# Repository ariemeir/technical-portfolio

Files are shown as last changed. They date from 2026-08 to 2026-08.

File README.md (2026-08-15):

# Technical Portfolio — Arie Meir

Representative projects, published for reference.

**→ [Browse all source on GitHub](https://github.com/ariemeir/technical-portfolio)**

## Projects

### [RoboImplant](roboimplant/) — non-invasive spinal implant adjustment system

A motorized orthopedic implant that lengthens a spinal distraction rod without
surgery, for treating early-onset scoliosis in growing children. Full-stack
across four disciplines:

- **Embedded** — AVR C firmware on an ATmega1284P: real-time motor control via a
  DS1267 digital pot into a maxon ESCON servo controller, interrupt-driven
  rotation counting, and current-threshold coupling detection as the primary
  safety interlock.
- **Mobile** — Android clinician console over Bluetooth SPP, with a custom
  line-oriented ASCII protocol, live telemetry, 3D visualization, and patient
  records.
- **Electronics** — EAGLE schematic and board layout for the controller,
  including the analog current/voltage sensing chain.
- **Mechanical** — SolidWorks enclosure for the handheld driver unit.

<p align="center">
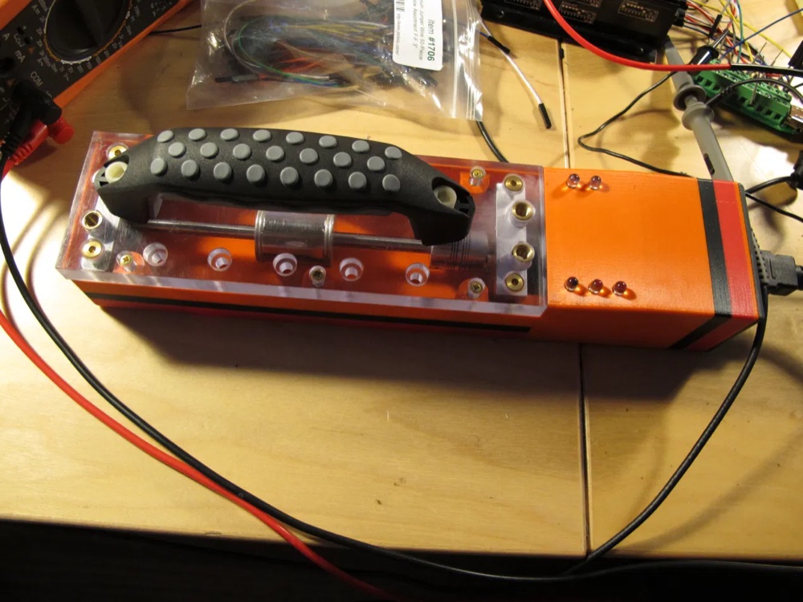
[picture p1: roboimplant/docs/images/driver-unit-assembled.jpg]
The assembled handheld driver unit in a 3D-printed orange enclosure with acrylic top plate.
  
  <br>
  <em>The handheld driver unit (v1)</em>
</p>

**→ [Read the one-page case study (PDF)](roboimplant/docs/roboimplant-case-study-arie-meir.pdf)**

Research prototype, ~2012–2013. Not a cleared medical device.
See [`roboimplant/NOTICE.md`](roboimplant/NOTICE.md) for rights and third-party
attribution.

---

### [3D Scanner](3dscanner/) — turntable photogrammetry rig

A DIY tabletop 3D scanner built to solve a real fabrication problem: an artist needed
larger and deeper variants of a commercially molded clay flower that existed only as a
physical object. It takes that object and produces a printable, watertight STL. Five
subsystems bound together by explicit contracts:

- **iOS** — **ScannerCam**, an iPhone camera server with a hand-rolled HTTP/1.1
  stack on `NWListener`: 13 REST routes, bearer auth with constant-time comparison,
  Keychain token storage, and hard locks on focus, exposure, and white balance.
  SwiftUI + AVFoundation, zero third-party packages.
- **Orchestration** — a Python session controller driving the scan loop across two
  machines, with idempotent retries, resumable sessions, and a five-stage SHA-256
  integrity chain from the phone's memory to the final archive.
- **Embedded** — an Arduino that controls the turntable by *impersonating its
  infrared remote*, replaying NEC codes reverse-engineered with a majority-vote
  capture sketch. No data port, no feedback, no encoder.
- **Reconstruction** — a Swift CLI over Apple Object Capture (RealityKit), chosen
  after COLMAP was tested and rejected for being CUDA-only on Apple Silicon.
- **Print prep** — a PyMeshLab pass that makes the mesh watertight, orients it by
  PCA, and scales it to real millimetres for printing and silicone-mold casting.

<p align="center">
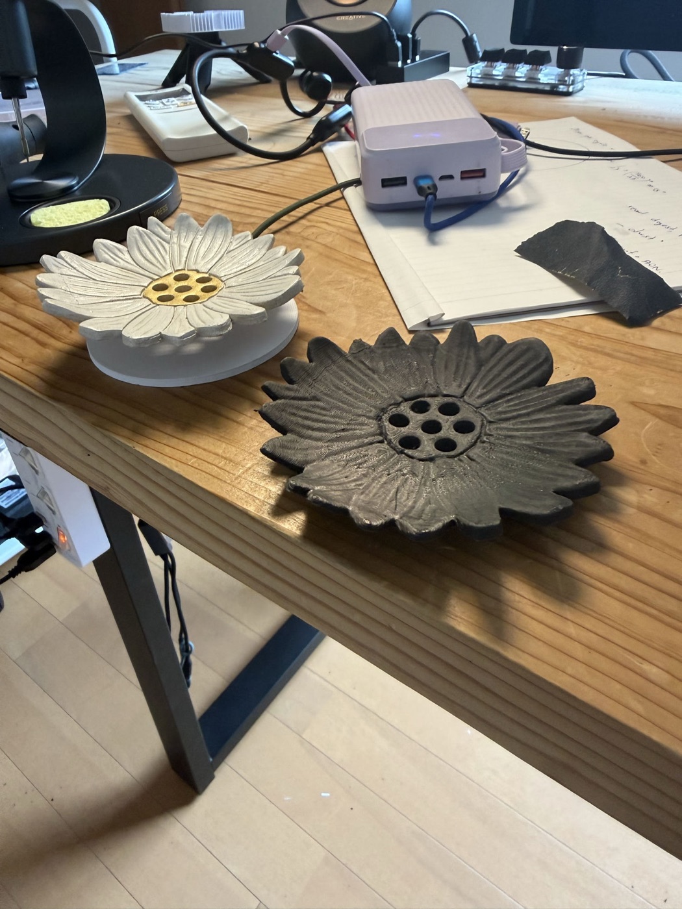
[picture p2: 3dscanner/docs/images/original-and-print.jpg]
A white ceramic daisy dish beside a dark grey 3D-printed copy of the same flower, both with ridged petals and a ring of holes through the centre.
  
  <br>
  <em>Input and output: the original ceramic dish, and a printed reproduction
  scanned from it.</em>
</p>

```
object ─→ 72 photos ─→ pose solve ─→ textured mesh ─→ watertight STL ─→ printed master
          locked        Object          USDZ/OBJ        PyMeshLab         silicone mold
          optics        Capture                         repair            → cast copies
```

The engineering centrepiece is control of an actuator that cannot be observed: the
turntable answers only to a fire-and-forget infrared *toggle*, so the controller
tracks an explicit assumed state and halts for human realignment on any ambiguity
rather than guessing and silently desynchronising the scan.

**→ [Read the one-page case study (PDF)](3dscanner/docs/3dscanner-case-study-arie-meir.pdf)**
· [Engineering log](3dscanner/docs/engineering-log.md)
· [Technical spec](3dscanner/docs/scannercam_spec.md)

Personal project, 2026. Working single-operator rig at late-prototype maturity.
See [`3dscanner/NOTICE.md`](3dscanner/NOTICE.md) for rights and attribution.

---

### [WifeSignal](wifesignal/) — a traffic light for the office door

A three-colour desk lamp that lets one person in the house tell another *how much
this can wait*. The office is a separate building: music on, windows closed, phone
face-down and unchecked for hours — which is the point, and which makes it a sealed
box. Text-and-hope fails when it matters; walking over always costs an interruption
whether or not the thing was urgent. The missing piece was never notification, it
was **priority expressed before the interruption happens**. Five components across
four disciplines:

- **iOS** — a SwiftUI app in 333 lines with no third-party packages and no
  Bluetooth: three priority buttons, a 5 s status poll, and a *Waiting… → Seen ♥*
  acknowledgement card that closes the loop for the sender.
- **Server** — a 290-line aiohttp + bleak bridge on a Mac, sharing one asyncio event
  loop, that exists because an iPhone cannot reliably be a BLE central for a device
  in another building. Bearer auth with constant-time comparison, exposed to a
  Tailscale tailnet only.
- **Embedded** — ESP32-C3 firmware over NimBLE exposing one service, one
  characteristic, one byte, with physical button presses as the acknowledgement path.
- **Electronics** — a custom two-layer KiCad board: three low-side lamp drivers,
  entirely through-hole, shaped and notched to match the enclosure.
- **Mechanical** — a 440-line Fusion 360 *script* that generates the two-part
  enclosure from derived dimensions, versioned in-band and guarded step by step.

<p align="center">
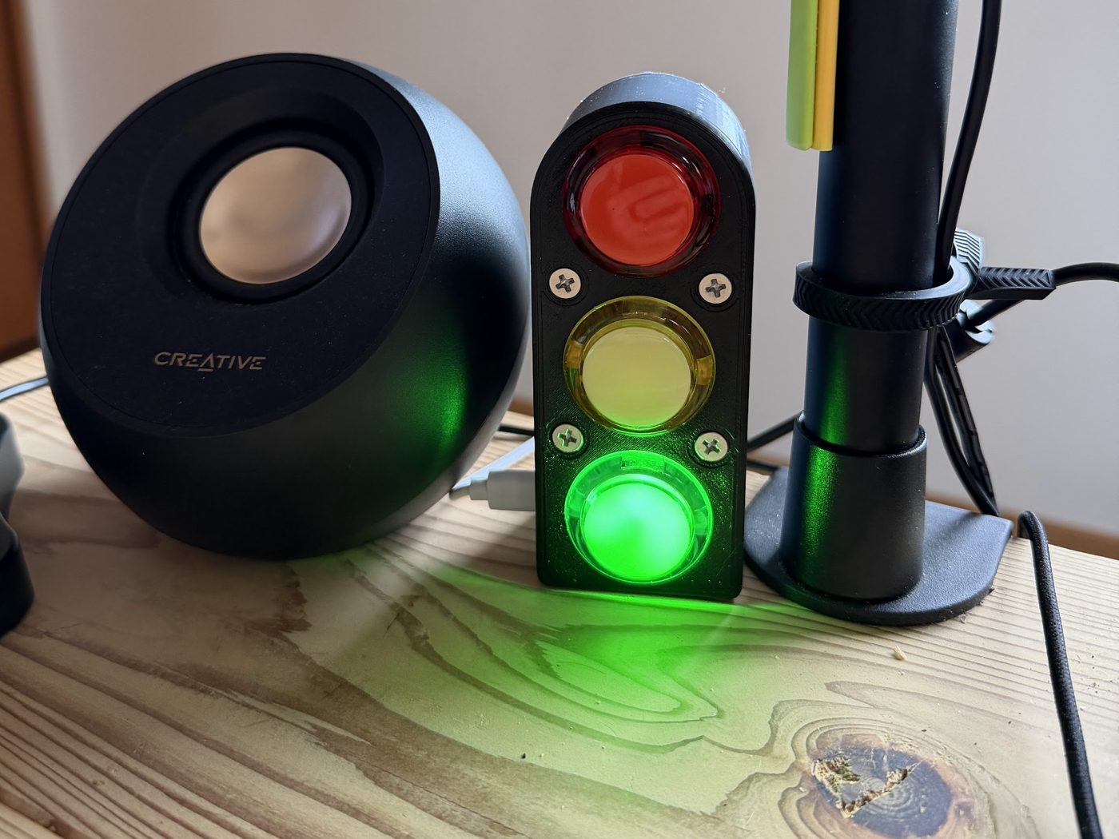
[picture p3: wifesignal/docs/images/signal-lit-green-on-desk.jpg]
A small black 3D-printed traffic light standing on a pale wooden desk beside a round black speaker. Its red and yellow lenses are dark; the bottom green lens glows brightly and casts a pool of green light across the desk.
  
  <br>
  <em>Green — <strong>whenever you're free</strong>. The speaker beside it is the
  reason the project exists.</em>
</p>

```
tap ─→ HTTPS ─→ aiohttp ─→ 1 byte ─→ ESP32-C3 ─→ lamp ─→ physical ─→ "Seen ♥"
       tailnet   desired    over BLE   NimBLE              press       on her
       only      state                                     = ack       phone
```

The engineering centrepiece is the return path. Because the state characteristic is
bidirectional, three different events — the server's own write echoed back, a human
pressing the button, and a device that has drifted — all arrive as an identical
one-byte notification. They are separated with no timers, correlation IDs, or
sequence numbers: every notify is simply compared against the state the server
already intends, which collapses the whole problem into three branches and makes
recovery after a reboot or a reflash automatic.

**→ [Read the one-page case study (PDF)](wifesignal/docs/wifesignal-case-study-arie-meir.pdf)**
· [Full case study](wifesignal/) · [Server](wifesignal/server/) · [iOS app](wifesignal/app/)
· [Firmware](wifesignal/firmware/) · [Hardware](wifesignal/device/)

Personal project, 2026. In daily use.
See [`wifesignal/NOTICE.md`](wifesignal/NOTICE.md) for rights and attribution.

---

Each project directory carries its own README and rights notice. Unless stated
otherwise in a project's `NOTICE.md`, this work is published for reference only
and is not offered under an open-source license.

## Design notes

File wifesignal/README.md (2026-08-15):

# WifeSignal — A Traffic Light for the Office Door

A three-colour desk lamp that lets one person in the house tell another *how much
this can wait*, without a phone, a notification, or an interruption. An iPhone app
sends a priority; a Mac in the office translates it to Bluetooth Low Energy; a
custom PCB lights one of three illuminated arcade buttons. Pressing that button
acknowledges the message, and the sender's phone shows **Seen ♥**.

<p align="center">
  A small black 3D-printed traffic light standing on a pale wooden desk beside a round black speaker. Its top lens is red and its middle lens is yellow, both dark; the bottom lens glows bright green and casts a pool of green light across the desk surface.
  <br>
  <em>The whole point of the project in one frame: green — <strong>whenever you're
  free</strong>. The speaker beside it is the reason the system exists. With music
  on and the windows closed, the office is acoustically sealed off from the house,
  and the phone is face-down and ignored on purpose. The light is the one channel
  that gets through without breaking concentration.</em>
</p>

Built 2026. Author: Arie Meir. Personal project — see [NOTICE.md](NOTICE.md).

**→ [Read the one-page case study (PDF)](docs/wifesignal-case-study-arie-meir.pdf)**
· [Server](server/) · [iOS app](app/) · [Firmware](firmware/) · [Hardware](device/)
· [Browse the source on GitHub](https://github.com/ariemeir/technical-portfolio/tree/main/wifesignal)

> **Reference only.** A working system in daily use, published so the engineering
> can be read. Deployment specifics (signing team, App Store Connect key IDs,
> Tailscale hostname, absolute paths) have been replaced with placeholders. No
> credential or token appears anywhere in this directory.

---

## The problem

The office is a separate building, a short walk from the house. Work there happens
with music on and the windows closed, which is exactly the point — and which makes
it a sealed box. The phone is face-down and unchecked for hours at a time, by
design.

That produces a genuinely asymmetric problem for the household. A message that
means *call your mother back sometime this week* and a message that means *the
delivery driver is leaving in thirty seconds* arrive through the same silent
channel and get read at the same time, which is to say eventually. The available
options were both bad: text and hope, which fails when it matters, or walk over,
which always works and always costs an interruption regardless of whether the
thing was urgent.

The missing piece was never notification. It was **priority, expressed before the
interruption happens**. The system had to satisfy four constraints:

- **Glanceable, not readable.** The signal must land in peripheral vision without
  pulling attention into a screen. Deciding whether to break focus should not
  itself break focus.
- **Three levels, not a text box.** Composing a message is work for the sender and
  ambiguity for the receiver. Three buttons removes both.
- **Acknowledgement must flow back.** A signal that vanishes into silence is worse
  than no signal — the sender is left wondering whether to walk over anyway. The
  loop only closes when she can see that it landed.
- **It cannot depend on the phone being looked at.** Which rules out every
  push-notification solution, since that is the failure mode being designed around.

The result is a shared vocabulary of three words — **Whenever**, **Soon**, **Now**
— with a physical object in the room that speaks it.

<p align="center">
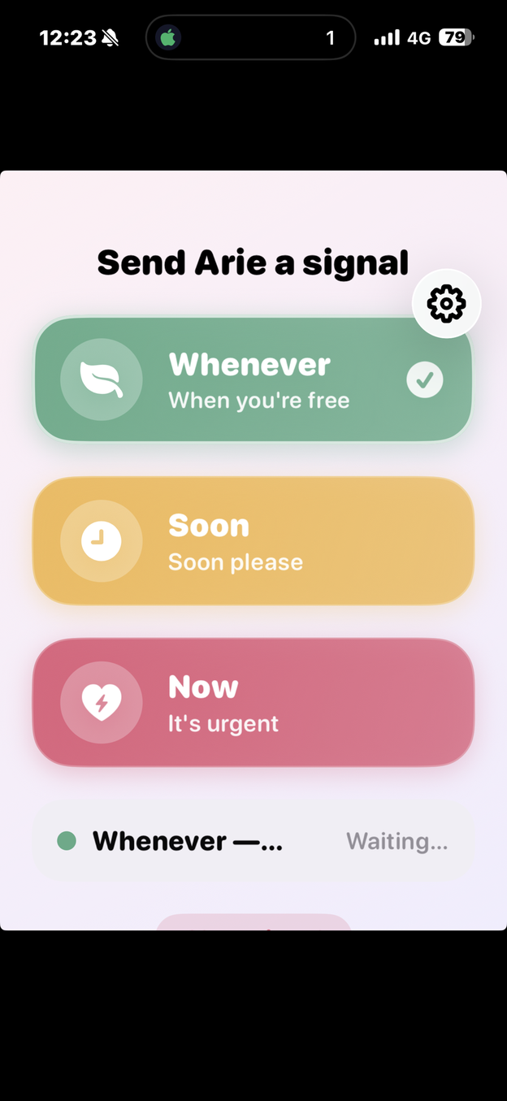
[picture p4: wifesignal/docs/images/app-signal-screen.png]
An iPhone screen titled 'Send Arie a signal' with three large rounded buttons stacked vertically: a green one labelled Whenever, 'When you're free', with a leaf icon and a tick; a yellow one labelled Soon, 'Soon please', with a clock icon; and a red one labelled Now, 'It's urgent', with a heart-and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
  
  <br>
  <em>The sender's whole interface. The palette is deliberately soft — the urgent
  case is a <em>rose</em>, not a fire-alarm red, and its icon is
  <code>bolt.heart.fill</code>. This is a channel between two people who like each
  other, not an alerting console. The status row is the acknowledgement path:
  <strong>Waiting…</strong> until the button is physically pressed, then
  <strong>Seen ♥</strong>.</em>
</p>

## How it works

Five components, four protocol boundaries, and one byte that carries the entire
system state.

```
┌─────────────┐   HTTPS + Bearer    ┌──────────────────┐    BLE GATT    ┌──────────────┐
│  iPhone app │ ──────────────────► │  aiohttp server  │ ─────────────► │  ESP32-C3    │
│  (SwiftUI)  │   tailnet only      │  (Mac, launchd)  │   1 byte       │  + 3 lamps   │
│             │ ◄────────────────── │                  │ ◄───────────── │              │
└─────────────┘   GET /v1/status    └──────────────────┘   NOTIFY       └──────────────┘
                  every 5 s                                             physical press
                                                                        = acknowledge
```

The architectural keystone is the middle box, and it exists for one reason: **an
iPhone cannot be a reliable BLE central for a device in another building.** iOS
suspends background Bluetooth work aggressively, and the phone is frequently not
in the office at all. So the phone never speaks Bluetooth. A Mac that is already
sitting three metres from the lamp, already powered, already on the network, takes
that role permanently. Everything else in the stack — the Tailscale tunnel, the
launchd job, the macOS Bluetooth permission grants — is the price of that single
decision, and it is worth paying: the phone's job shrinks to an authenticated HTTP
POST, which is a thing phones do perfectly.

Transport is [Tailscale](https://tailscale.com) `serve`, not a public tunnel. The
API is reachable only from devices on the tailnet, over a real Let's Encrypt
certificate, with the second phone joined by **node sharing** so it resolves the
one host and sees nothing else on the network. The bearer token is the inner
layer; the tailnet ACL is the wall.

## One byte on the wire

The BLE contract is a single characteristic carrying a single byte:

| Value | Meaning |
|---|---|
| `0x00` | all lamps off |
| `0x01` | red — *Now* |
| `0x02` | yellow — *Soon* |
| `0x03` | green — *Whenever* |

Three channels addressed **by value, not by bitmask**. That choice is doing real
work. The product rule is *exactly one signal is active at a time*, and encoding
the channels as a bitmask would have made "red and green simultaneously" a
representable state — one that every layer would then need to defend against. As
an enumeration, the illegal state cannot be expressed on the wire at all. There is
no validation code for it anywhere in the server or the firmware, because there is
nothing to validate.

The same byte is read, written, and notified, which is what makes the
acknowledgement path collapse into almost nothing: the device does not need a
separate "ack" message, because setting the state to `0` *is* the acknowledgement.

## Telling your own echo from a human being

This is the interesting problem in the system, and it comes directly from that
economy. Because the state byte is bidirectional, the server has to distinguish
three events that arrive through the identical mechanism — a `NOTIFY` carrying one
byte:

1. **Its own write, echoed back.** The firmware notifies subscribers whenever the
   characteristic changes, including when the change came from the server itself.
2. **A physical button press**, which is the acknowledgement and the entire reason
   the return path exists.
3. **Drift** — the device holding a state that disagrees with the server, after a
   reboot, a reflash, or a button press while idle.

The conventional fixes are correlation IDs, sequence numbers, or a suppression
window timed around each write. All three add state, and the timer-based one is
subtly wrong under load. The server instead exploits the fact that it already
knows what the lamps *should* show, in a variable named `desired_state`, and
classifies every incoming notify by comparing against it:

| Notify value | vs. `desired_state` | Interpretation | Action |
|---|---|---|---|
| equal | — | echo of our own write | ignore |
| `0` | non-zero | **physical press** | mark acknowledged, timestamp it |
| anything else | mismatch | drift | re-assert `desired_state` |

Three branches, no timers, no message IDs, no sequence numbers. The third branch is
load-bearing in a way that is easy to miss: it is simultaneously the anti-drift
mechanism *and* the hook for a future "ping back" feature, where a press from idle
would signal in the other direction. Today the server writes that press straight
back to off, which is the correct conservative behaviour for a feature whose
semantics have not been decided.

## Converging instead of queueing

`desired_state` is defined as a pure function of the signal: *the colour byte iff a
signal is active and un-acknowledged, else zero.* HTTP handlers never touch
Bluetooth. They mutate state under an `asyncio.Lock` and set an
`asyncio.Event`; a single BLE task owns the `BleakClient` and performs every write.

There is **no queue and no retry list**, which is the point. A burst of taps
coalesces into one write of the latest value, because last-write-wins is exactly
right for a lamp — nobody wants a backlog of stale colours replayed at them. More
importantly, the same property makes recovery free. The reconnect loop re-writes
`desired_state` immediately on every successful connect, so a device that rebooted,
lost power, or was reflashed mid-signal comes back showing the correct colour
without anyone noticing, and without a single line of reconciliation logic.

Convergence, not delivery. The server never asks *did that message arrive?* — it
continuously asserts *this is what the lamps should show*, and any disagreement
resolves itself on the next connect. Around it sits an ordinary supervisor:
scan by service UUID, connect, subscribe, race the write-needed and disconnected
events, and back off exponentially from 1 s to a 30 s ceiling on failure.

## The soldered parts win

The lamp drivers on the assembled board are **S8550 PNP** transistors. The
schematic says **S8050 NPN**. They came from the same assortment kit, the part
numbers differ by one character, and the mistake was found only after the board was
populated and the lamps behaved backwards.

A PNP low-side driver inverts the control logic: **GPIO LOW turns the lamp on.**
The fix was one line in `applyLamps()` and a comment in capital letters telling the
next engineer not to "correct" it back. Reworking three transistors on a working
board would have bought nothing except the satisfaction of matching a drawing.

The second-order consequence was subtler and took longer to find. A pin that has
not yet been configured as an output floats, and a floating base on a PNP driver
reads as *on* — so all three lamps flashed at every boot. The fix is an ordering
trick that is worth knowing: **drive the pin high, then call `pinMode(OUTPUT)`,
then drive it high again.** The first write latches the level into the output
register before the driver is enabled, so the pin never passes through an undefined
state on its way to being an output.

The schematic in this repository is therefore **knowingly wrong**, and documented
as such. That is the honest artifact of a physical project: the drawing describes
an intention, the board describes reality, and the firmware is written against
reality.

## Failures that make no sound

Every hard bug in this project failed silently. None threw an exception; all of
them just quietly did nothing, which is the worst possible behaviour and the reason
the codebase is structured around detecting symptoms rather than catching errors.

**macOS returns empty Bluetooth scans when permission is missing.** Not an error,
not a prompt — an empty list, indistinguishable from "no devices nearby". The scan
function therefore counts how many advertisements it saw *at all*, and when the
count is zero it logs a warning naming the actual cause and the exact System
Settings pane. The launchd-run interpreter needs its own grant, separate from the
one Terminal inherits, and the grant is attached to the Python binary's path — so a
Homebrew upgrade silently revokes it.

**macOS also hides advertised device names**, returning `None` for all of them, so
name-based matching finds nothing forever. All matching in this project is by
service UUID, in three separate files, each with a comment explaining why.

**A `snake_case` JSON key would have silently decoded to `nil`** in Swift rather
than throwing. The server's responses are deliberately camelCase (`sentAt`,
`acknowledgedAt`) with a comment on both sides of the boundary recording that the
iOS app decodes with a bare `JSONDecoder` and would drop the timestamps without
complaint.

**A folder move broke the LaunchAgent without a single log line.** Absolute paths
in the plist and in the ops script pointed at the old location; launchd simply
declined to start the job. In the published copy those paths are placeholders
(`__PROJECT_DIR__`, `__HOME__`) and the ops script derives its own location, which
is what should have been true from the start.

**The device accepts exactly one BLE central.** The test CLI and the server cannot
both be connected, and the failure looks like an unrelated timeout. Documented at
the top of every file that connects.

## From breadboard to fabricated board

Four stages, roughly two weeks, each one earning the next.

| | |
|:--:|:--:|
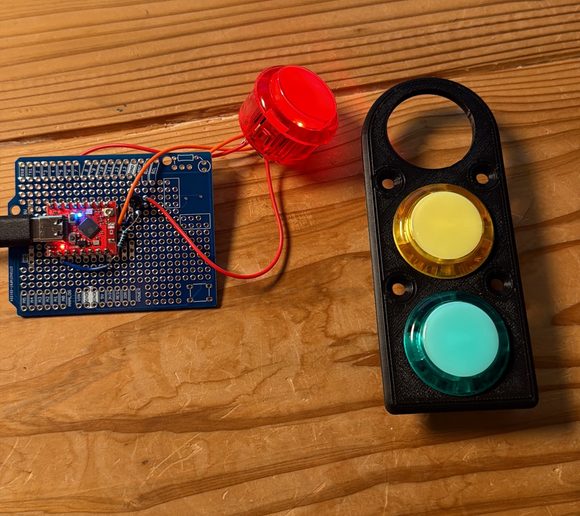
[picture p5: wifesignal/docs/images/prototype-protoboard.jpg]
An Arduino-style prototyping shield on blue perfboard with a small red microcontroller board soldered to it, wired with red jumper wire to a single large red illuminated arcade button. Beside it lies a black 3D-printed faceplate holding a yellow and a green arcade button, with an empty circular cut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
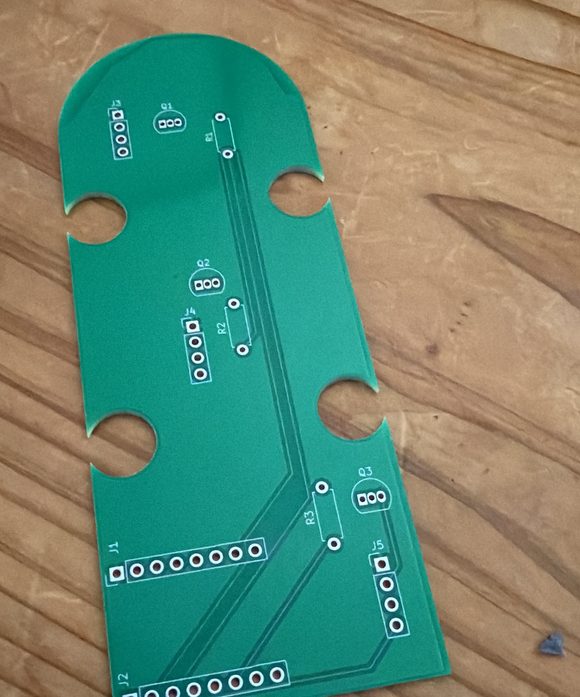
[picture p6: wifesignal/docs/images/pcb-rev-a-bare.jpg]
A bare green printed circuit board on a wooden desk, rounded at one end and square at the other, with four semicircular notches cut into its long edges. White silkscreen marks three transistor outlines labelled Q1, Q2 and Q3, three resistor footprints R1 to R3, and two eight-pin headers J1 and J2.
|  |  |
| **1. One channel on protoboard.** A single button and lamp, proving the BLE service, the button semantics and the inverted lamp polarity before committing to a layout. The faceplate beside it is already the target shape. | **2. Rev A, fabricated.** Three identical channels: GPIO → 1 kΩ → transistor base, emitter to ground, collector to lamp cathode. Entirely through-hole, two layers, no vias. The four edge notches are not decoration — see below. |
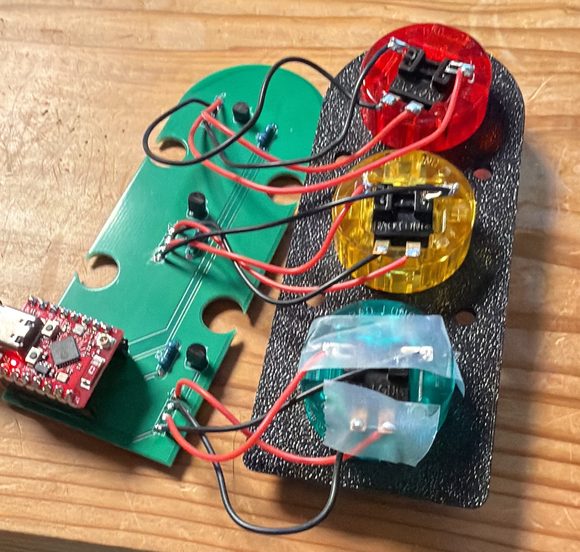
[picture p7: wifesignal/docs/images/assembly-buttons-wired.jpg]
The green circuit board wired to a black 3D-printed faceplate holding red, yellow and green illuminated arcade buttons. Red and black wire pairs run from board headers to each button's lamp and switch terminals. A small red ESP32-C3 module is seated on female headers at the lower left of the board.
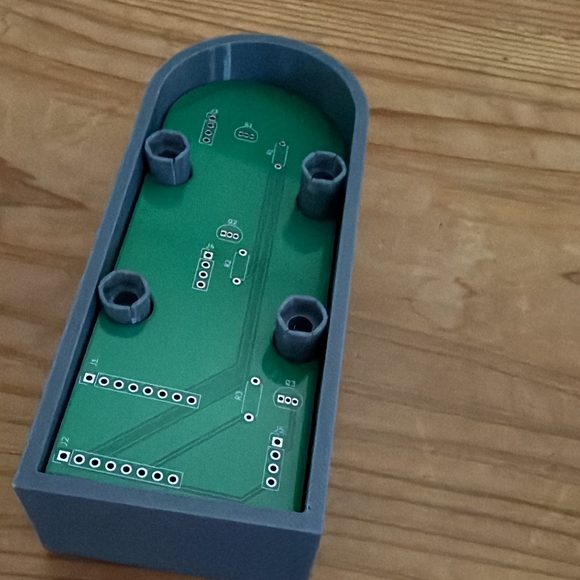
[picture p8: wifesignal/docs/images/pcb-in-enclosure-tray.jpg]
The green circuit board resting inside a grey 3D-printed tray, supported on four dark hexagonal pillars that pass through the notches in the board's edges. A yellow sticky note lies on the desk above.
|  |  |
| **3. Assembled.** The ESP32-C3 sits on female headers, so it is removable and the board is not scrap if the module dies. Each button is a four-wire part: lamp anode and cathode, switch common and normally-open. | **4. In the enclosure.** The board drops over four M4 pillars — the notches at (±16, ±18.5) mm are cut to clear them exactly. The electrical and mechanical designs are dimensionally coupled, and both say so in comments. |

The pin assignment carries one hard-won rule: **GPIO 2, 8 and 9 are strapping pins
and 20/21 are UART0** on the ESP32-C3, so all five are avoided. Strapping pins are
sampled at boot to decide boot mode; hanging a lamp driver off one produces a board
that works perfectly until the day it refuses to start.

| | Red | Yellow | Green |
|---|---|---|---|
| **switch** | GPIO3 | GPIO4 | GPIO5 |
| **lamp** | GPIO6 | GPIO7 | GPIO10 |

Buttons are `INPUT_PULLUP` with common tied to ground, so a press reads LOW,
debounced at 40 ms with a per-button handled flag.

## An enclosure that is a program

The enclosure is not an STL and not a saved CAD file. It is a **440-line Python
script that generates the entire two-part enclosure inside Autodesk Fusion 360**,
and it is the declared source of truth — the design is rebuilt from code, not
edited by hand.

That is not novelty for its own sake. It buys the same things version-controlled
code always buys, in a domain where they are usually unavailable:

- **Dimensions are derived, not typed.** The body width is
  `BUTTON_HOLE_DIA + 2 × SIDE_MARGIN`; the height is `BUTTON_SPACING × 2 + 2 ×
  END_MARGIN`. Changing the button diameter reshapes the whole enclosure
  consistently, instead of leaving four stale numbers behind.
- **Physical measurements are named constants.** The USB-C window's vertical extent
  is computed from the measured height of the connector above the PCB and the
  thickness of the spacer stack, not eyeballed against a screen.
- **The build is versioned in-band.** `VERSION = "v15"` with a build stamp, printed
  to a dialog on completion, so the running copy can be identified — the script
  lives in two places and drift is otherwise invisible.
- **Fragile operations are individually guarded.** Fillets and countersinks are the
  features most likely to fail on a given geometry, so each is wrapped and reports
  `built | FAILED | skipped` rather than aborting the run and losing everything.

The visible result of iterating in code is a redesign that would have been painful
by hand: v12 held the bare dev board on edge in a printed cradle; v15 deletes the
cradle entirely, deepens the tray from 30 mm to 37 mm, and bolts the custom PCB
flat to four pillars — the change that turned a prototype holder into a product.

## Repository layout

| Path | Contents |
|---|---|
| [`server/`](server/) | The whole bridge: aiohttp HTTP API + bleak BLE central, 290 lines, one file, one event loop. Plus a standalone BLE test CLI. |
| [`app/`](app/) | SwiftUI iPhone app, 333 lines across 7 files. XcodeGen spec; no `.xcodeproj` in the repo. |
| [`firmware/`](firmware/) | ESP32-C3 firmware (NimBLE-Arduino). The current 3-channel build, plus the 1-channel bring-up sketch kept as reference. |
| [`device/WifeSignalPCB/`](device/WifeSignalPCB/) | KiCad project and fabrication output. `WifeSignal3ch` is the board that was made. |
| [`device/enclosure/`](device/enclosure/) | The Fusion 360 generator script — the CAD source of truth. |
| [`ops/`](ops/) | launchd LaunchAgent template and the `up/down/restart/status/logs/ack` operator script. |

## The HTTP API

All JSON, all bearer-authenticated except `/health`, which ops tooling needs to
reach before it can know whether anything else works.

| Method | Path | Purpose |
|---|---|---|
| `POST` | `/v1/signal` | `{"color": "green"\|"yellow"\|"red"}` — set the signal, light the lamp |
| `POST` | `/v1/clear` | Wipe the signal, all lamps off |
| `POST` | `/v1/ack` | Acknowledge without clearing the colour — the CLI equivalent of a physical press |
| `GET` | `/v1/status` | Polled by the app every 5 s |
| `GET` | `/health` | Unauthenticated; reports `deviceConnected` |

Token comparison is constant-time via `hmac.compare_digest`, and the server refuses
to start with an empty token rather than defaulting to open. Device liveness is
surfaced to the app as a soft field rather than an error, so a disconnected lamp
degrades the UI instead of breaking it.

## The BLE contract

| | |
|---|---|
| Service UUID | `6d5f0001-4b6b-4a3a-9e1e-2a7b1c9f0001` |
| STATE characteristic | `6d5f0002-4b6b-4a3a-9e1e-2a7b1c9f0002` |
| Properties | `READ` \| `WRITE` \| `NOTIFY`, 1 byte |
| Advertising | Service UUID in the advertisement, 100–200 ms interval |
| Matching | **By service UUID only** — macOS reports advertised names as `None` |

Firmware button semantics, which must stay in lockstep with the server's
classification table: a press while `state != 0` sets `0` and notifies (that is the
acknowledgement); a press while `state == 0` sets that button's colour, which the
server writes back off.

## State of the code

A working system in daily use, honestly described. What that means:

- **The acknowledgement is not instant.** It arrives on the next 5 s poll. A
  WebSocket rewrite was considered and explicitly rejected — polling is
  imperceptible at this cadence and the HTTP stack was already deployed and proven.
- **The app only sees acknowledgements while foregrounded.** Polling is a plain
  `Task` loop that never pauses in the background, and there is no
  `BGTaskScheduler` and no push. For the sender's actual usage — open the app, tap,
  watch for *Seen* — this is fine, and it is still a real limitation.
- **Poll failures after the first success are swallowed.** The error is only
  surfaced when there is no status at all, so a server that dies mid-session leaves
  the last-known state on screen without a warning.
- **The API token lives in `UserDefaults`, not the Keychain.** Acceptable only
  because the API is tailnet-only and can do nothing but change a lamp colour; it
  should still be in the Keychain.
- **URL validation is `URL(string:) != nil`**, which accepts very nearly anything.
- **The schematic disagrees with the built board** on the transistor part number,
  deliberately and with the reason documented in three places.
- **The 1-channel PCB variant was never routed or fabricated.** It is kept as a
  design-history artifact; only `WifeSignal3ch` exists physically.
- **A "ping back" path is stubbed but not designed.** The hook is live in the
  notify handler; the semantics are undecided, so a press from idle is currently
  written straight back to off.

## Key sources

| File | Why it's worth reading |
|---|---|
| [`server/server.py`](https://github.com/ariemeir/technical-portfolio/blob/main/wifesignal/server/server.py) | The whole bridge in 290 lines. The `on_notify` classifier and the `ble_loop` supervisor are the heart of the system. |
| [`firmware/wifesignal_3ch/wifesignal_3ch.ino`](https://github.com/ariemeir/technical-portfolio/blob/main/wifesignal/firmware/wifesignal_3ch/wifesignal_3ch.ino) | The PNP polarity note and the latch-before-`pinMode` boot-flash fix, with the button semantics documented as a contract with the server. |
| [`app/WifeSignal/SignalViewModel.swift`](https://github.com/ariemeir/technical-portfolio/blob/main/wifesignal/app/WifeSignal/SignalViewModel.swift) | 38 lines: the poll loop and its deliberately forgiving — and knowingly flawed — error policy. |
| [`app/WifeSignal/ContentView.swift`](https://github.com/ariemeir/technical-portfolio/blob/main/wifesignal/app/WifeSignal/ContentView.swift) | The entire UI, including the *Waiting… → Seen ♥* status card. |
| [`device/enclosure/AWifeSignalEnclosure.py`](https://github.com/ariemeir/technical-portfolio/blob/main/wifesignal/device/enclosure/AWifeSignalEnclosure.py) | Parametric CAD as a program: derived dimensions, measured constants, guarded feature steps. |
| [`device/WifeSignalPCB/WifeSignal3ch.kicad_sch`](https://github.com/ariemeir/technical-portfolio/blob/main/wifesignal/device/WifeSignalPCB/WifeSignal3ch.kicad_sch) | The schematic, including the in-drawing notes mapping refs to channels — and the wrong transistor. |
| [`ops/wife-signal`](https://github.com/ariemeir/technical-portfolio/blob/main/wifesignal/ops/wife-signal) | launchd bootstrap, health polling, and Tailscale serve configuration in one operator script. |
| [`server/wifesignal_cli.py`](https://github.com/ariemeir/technical-portfolio/blob/main/wifesignal/server/wifesignal_cli.py) | 69-line BLE REPL for talking to the board directly when the server is stopped. |

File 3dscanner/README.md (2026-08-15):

# 3D Scanner — Turntable Photogrammetry Rig

A DIY tabletop 3D scanner that turns a physical object into a printable, watertight
STL. An iPhone runs a from-scratch HTTP camera server; a Mac orchestrates the scan;
an Arduino drives the turntable by impersonating its infrared remote; Apple Object
Capture reconstructs the mesh; a PyMeshLab pass prepares it for printing and casting.

<p align="center">
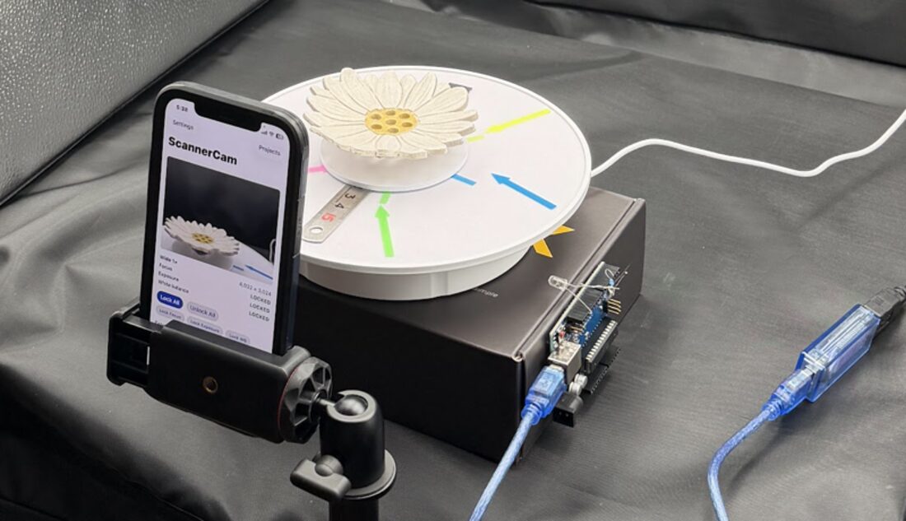
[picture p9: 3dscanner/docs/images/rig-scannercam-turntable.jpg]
Close view of the rig: an iPhone running ScannerCam on a tripod mount showing a live preview and three status rows reading LOCKED, facing a white turntable holding a ceramic daisy dish, with an Arduino and its infrared LED aimed at the turntable from the right.
  
  <br>
  <em>The whole capture loop in one frame. The phone runs <strong>ScannerCam</strong>
  with focus, exposure and white balance all reading <code>LOCKED</code> — a state the
  controller can <em>require</em> before it will record a single frame. At right, the
  Arduino's IR LED points at the turntable across open air: the only link between them,
  and a one-way one.</em>
</p>

Built 2026. Author: Arie Meir. Personal project — see [NOTICE.md](NOTICE.md).

**→ [Read the one-page case study (PDF)](docs/3dscanner-case-study-arie-meir.pdf)**
· [Engineering log](docs/engineering-log.md)
· [ScannerCam technical spec](docs/scannercam_spec.md)
· [Browse the source on GitHub](https://github.com/ariemeir/technical-portfolio/tree/main/3dscanner)

> **Reference only.** A working single-operator rig at late-prototype maturity,
> published so the engineering can be read. Deployment specifics (device IDs,
> network addresses, signing team) have been replaced with placeholders.

---

## The problem

An artist wanted **larger versions of a commercially molded clay flower**, and to
explore deeper forms without changing the diameter. The obstacle was that the
geometry existed only as a physical object — there was no model to scale, deepen, or
re-cut. Getting one meant capturing the real surface accurately enough to modify,
re-fabricate, and eventually use as the basis for new mold tooling.

Photogrammetry — reconstructing 3D geometry from overlapping photographs — is the
right tool, but it needs dozens of images from evenly spaced angles shot under
*identical* optical conditions. Commercial turntable scanners exist and cost
accordingly. The parts to build one do not: a motorized photography turntable is
inexpensive, and a modern phone has a better sensor than most dedicated scanner
cameras.

The gap is control. The turntable obeys an infrared remote and has no data port.
The phone's camera app will happily refocus and re-meter between shots, which
destroys the reconstruction. Nothing talks to anything else.

This project closes that gap end-to-end: object in, printable mesh out, with every
frame verified byte-for-byte along the way — and the loop is closed, since the
scanned flower came back as a printed reproduction.

## How it works

```
   ┌──────────────┐                            ┌────────────────────────────┐
   │ IR remote    │  reverse-engineered        │  iPhone — "saru"           │
   │ 14 NEC codes │  → turntable_codes.json    │  ScannerCam (SwiftUI)      │
   └──────┬───────┘                            │  ┌──────────────────────┐  │
          │ replayed                           │  │ HTTP/1.1 server      │  │
          ▼                                    │  │ NWListener, 13 routes│  │
   ┌──────────────┐   serial ASCII 115200      │  │ bearer auth          │  │
   │ Arduino Uno  │◄───────────────────┐       │  └──────────┬───────────┘  │
   │ IR LED / D3  │  PING→PONG         │       │  AVCapture: focus/exposure │
   └──────┬───────┘  R <rawhex>        │       │  /WB LOCKED for the run    │
          │ 38 kHz                     │       └─────────────┬──────────────┘
          ▼                            │                     │ HTTP over
   ┌──────────────┐                    │                     │ Wi-Fi / Tailscale
   │  turntable   │            ┌───────┴─────────────────────┴───────┐
   │  (no data    │            │        Mac — "shika"                │
   │   port)      │            │  scan.py — session controller       │
   └──────────────┘            │  move → settle → capture → pull →   │
                               │  SHA-256 verify → next frame        │
                               └──────────────────┬──────────────────┘
                                                  │  scans/completed/<id>/
                                                  ▼  + tar.gz + checksums
                               ┌─────────────────────────────────────┐
                               │  Apple Object Capture (RealityKit)  │
                               │  objcap CLI → USDZ + OBJ → STL      │
                               └──────────────────┬──────────────────┘
                                                  ▼
                               ┌─────────────────────────────────────┐
                               │  repair.py (PyMeshLab)              │
                               │  weld → drop strays → close holes → │
                               │  orient → scale to mm → watertight  │
                               └─────────────────────────────────────┘
```

One scan is 36–72 frames. Each frame is: rotate by a timed IR pulse, wait for
vibration to settle, trigger the shutter over HTTP, download the JPEG, verify its
SHA-256, then move again. A 72-frame run plus reconstruction takes roughly five
minutes per loop on an M4.

<p align="center">
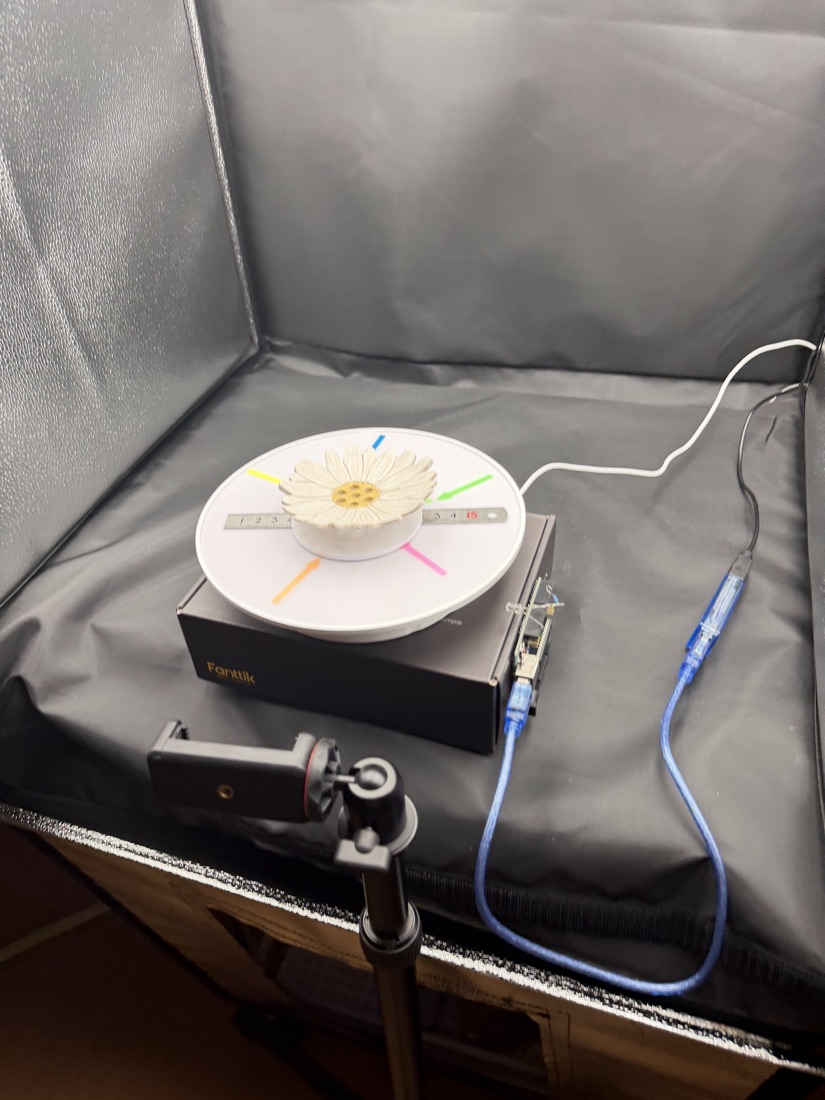
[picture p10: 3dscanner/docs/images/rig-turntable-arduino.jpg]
The motorized turntable raised on a box inside the light tent, with the Arduino board beside it and its infrared LED aimed at the turntable.
  
  <br>
  <em>The Arduino's IR LED, aimed across open air at the turntable — no wire connects
  them. The exact command codes were learned from the turntable's own remote using
  <code>capture_remote_signals.ino</code>, then replayed.</em>
</p>

The two machines carry codenames throughout the code and docs: **`saru`** is the
iPhone, **`shika`** is the Mac.

## Driving an actuator you cannot observe

This is the interesting control problem, and it shaped the whole controller.

<p align="center">
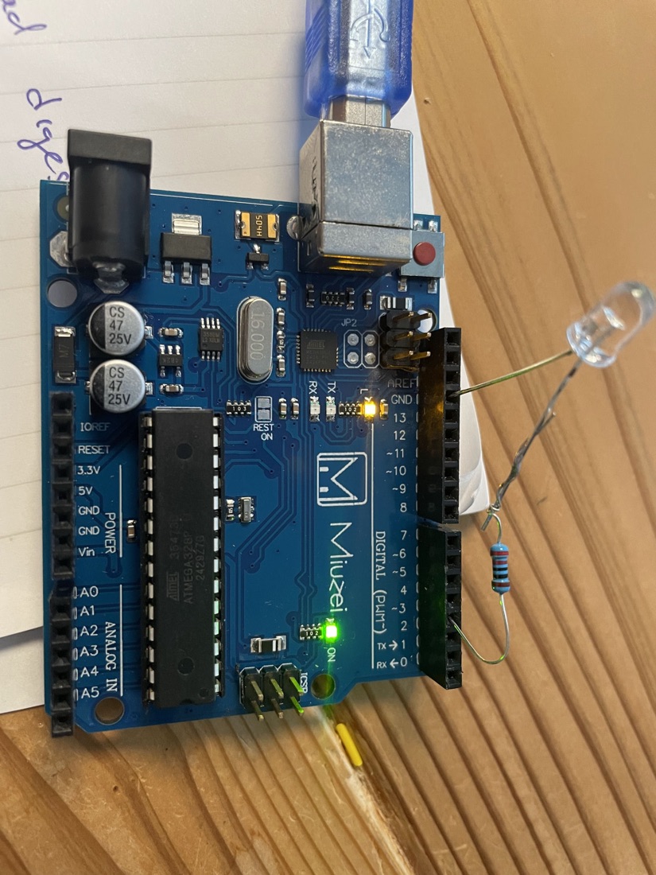
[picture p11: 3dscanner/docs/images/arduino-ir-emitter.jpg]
Close-up of an Arduino Uno with a clear infrared LED wired through a series resistor to the digital header, connected to a computer by a blue USB cable.
  
  <br>
  <em>The entire electrical interface to the turntable: one infrared LED on a series
  resistor, run off the Uno's digital header. <strong>Nothing connects to the turntable
  at all</strong> — it has no data port, so the Arduino simply impersonates its remote.
  The LED emits outside the visible band, so it looks equally dead whether or not it is
  working, which is exactly why <code>ir_dc_test.ino</code> exists: hold the pin high
  for three seconds and view it through a phone camera, where the emitter shows up as a
  violet glow. (The firmware header documents a 2N2222 driver stage for more range;
  this is the simpler direct-drive bring-up wiring.)</em>
</p>

The turntable's only relevant input is the remote's **`START_PAUSE` button — a
toggle**. There is no "stop" command, no position encoder, no feedback of any kind.
Infrared is fire-and-forget: the Arduino can emit a pulse but cannot confirm the
table received it. The controller therefore cannot *know* whether the table is
spinning; it can only track what it *assumes*.

So the assumption is made explicit. The driver keeps an `AssumedState` of
`STOPPED`, `RUNNING`, or `UNKNOWN`, and **any ambiguous toggle drops it to
`UNKNOWN`** — a failed start is ambiguous, and a failed stop is worse because the
table is probably still turning. From `UNKNOWN` the controller halts the session
and demands manual realignment. It never auto-toggles its way out, because a toggle
sent against an unknown state inverts every subsequent move and silently desyncs
the entire scan.

The same logic governs interruption. On `Ctrl-C` mid-move the controller
deliberately **does not** send an emergency stop — with a toggle-only actuator, a
"stop" command has an even chance of being a "start" command — and it says so in
its output rather than leaving the operator to guess.

Angle is open-loop: `run_seconds = degrees / degrees_per_second`, minus measured
command latency and coast time. This is approximate by construction, and that is
fine — Object Capture recovers true camera pose from image features, so nominal
angles only need to be even enough to give good coverage.

## Keeping the photographs identical

Photogrammetry fails quietly when the camera changes between frames. Autofocus
shifts effective magnification; auto-exposure changes brightness; auto white
balance shifts colour and produces visible texture seams. All three are on by
default on a phone.

ScannerCam exposes hard locks for focus, exposure, and white balance, and the API
lets the controller *require* them: a capture request with `require_locks: true`
is rejected with `409 camera_not_locked` unless all three are engaged. The camera
is also pinned to a single physical lens — no virtual/dual device, so iOS cannot
silently switch lenses and change the intrinsics mid-scan.

Locking the camera only fixes half of it; the scene has to hold still optically too.

<p align="center">
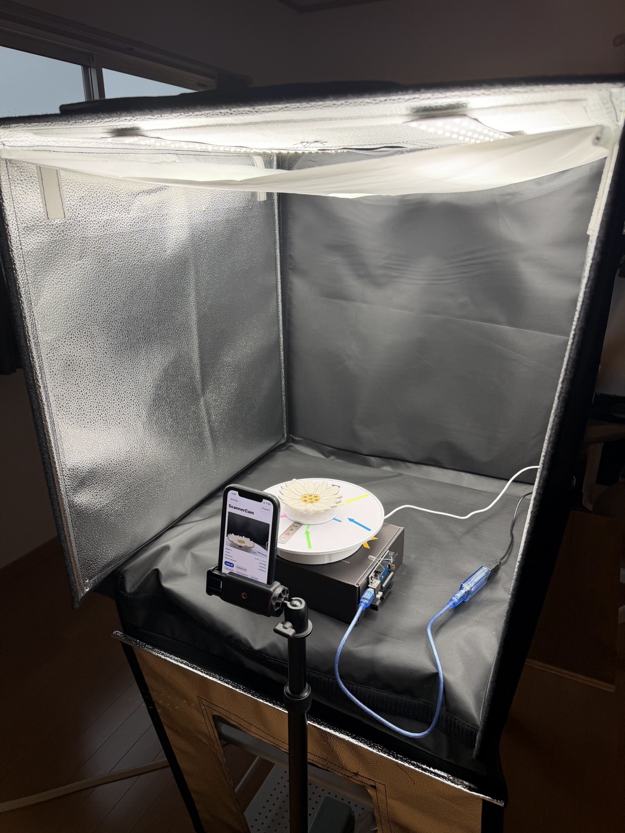
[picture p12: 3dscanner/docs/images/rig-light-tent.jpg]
The full rig inside a photo light tent with its LED panel lit, showing diffuse light falling on the turntable and a plain grey backdrop behind it.
  
  <br>
  <em>Why the light tent earns its place. It supplies flat, diffuse light with no hard
  moving shadows — and, less obviously, a <strong>plain matte backdrop</strong>. A
  feature-rich static background is the most reliable way to ruin a turntable scan: the
  object rotates, the background does not, and the solver cannot reconcile two rigid
  scenes moving relative to one another. The first attempt failed for exactly this
  reason, against a cluttered desk with a monitor showing text.</em>
</p>

## Integrity across three machines

A frame passes through a phone, a network, and a laptop before it is trusted. The
chain is unbroken:

1. The phone computes the JPEG's SHA-256 **in memory, before the file touches disk**.
2. That hash is returned in the capture response *and* served on download as both
   `ETag` and `X-ScannerCam-SHA256`.
3. The controller stream-hashes during download and compares against both.
4. The download lands as `frame_000034.jpg.part` and is `os.replace`d into position
   only after verification — an interrupted transfer can never masquerade as a good
   frame, and a leftover `.part` file is a hard validation failure.
5. At packaging, every frame is re-hashed from disk; the final archive gets its own
   `.sha256`.

Retries are idempotent by construction. The `request_id` for a capture is a
deterministic `uuid5(session_id, frame)`, so a retry is byte-identical and the
server returns the original capture instead of firing the shutter twice. And when
a capture fails *ambiguously*, the controller issues a `HEAD` for the remote frame
before re-firing — because the photo may actually have landed, and you do not
re-actuate physical hardware on uncertainty.

## Repository layout

| Path | Contents |
|---|---|
| [`capture/controller/`](capture/controller/) | `scan.py` + the session controller — scan loop, retry/idempotency, resumability, packaging. Python, stdlib + PyYAML + pyserial. 25 tests. |
| [`capture/iphone/`](capture/iphone/) | **ScannerCam** — the iOS camera-server app. SwiftUI + AVFoundation + Network.framework, zero third-party packages. |
| [`capture/protocols/`](capture/protocols/) | The API contract shared by both sides: `api_v1.md` and `constants.json` |
| [`firmware/turntable_ir/`](firmware/turntable_ir/) | Arduino sketches, the IR code table, and the `irctl.py` operator CLI |
| [`reconstruction/`](reconstruction/) | `objcap` Swift CLI over RealityKit, the shell pipeline, and `repair.py` print prep |
| [`docs/`](docs/) | The ScannerCam technical spec and the engineering log |
| [`config/`](config/) | `scanner.example.yaml` — the configuration template |

## The HTTP API

Local-network only, `http://<phone>:8765/api/v1`, bearer token, `snake_case` JSON.
Full reference in [`capture/protocols/api_v1.md`](capture/protocols/api_v1.md);
complete design rationale in [`docs/scannercam_spec.md`](docs/scannercam_spec.md).

| Method | Path | Purpose |
|---|---|---|
| `GET` | `/health` | Liveness. The only unauthenticated route; exposes nothing. |
| `GET` | `/status` | Camera state — lock flags, ISO, lens position, exposure duration |
| `POST` | `/captures` | Take one photo. Idempotent on `request_id`. |
| `GET` | `/projects` · `/projects/{id}` · `/manifest` | Project listing and metadata |
| `GET` | `/projects/{id}/images` | Cursor-paginated (`after_frame` / `has_more`) |
| `GET`/`HEAD` | `/projects/{id}/images/{frame}` | Download one JPEG; `HEAD` reports what `GET` would return |
| `DELETE` | image · project · all projects | Destructive routes require an `X-Confirm-Delete` echo header |
| `GET` | `/storage` | Free space, used bytes, project/image counts |

The server is hand-rolled HTTP/1.1 on `NWListener`. Scope was deliberately pinned:
**no keep-alive, no chunked encoding**, `Connection: close` on every response, always
an accurate `Content-Length`. That cut kept a from-scratch implementation tractable
and is documented rather than discovered — clients must not assume connection reuse.

## What the reconstruction stage actually runs

**COLMAP was evaluated and removed.** Its dense stereo (`patch_match_stereo`) is
CUDA-only and hard-errors on Apple Silicon, so on this hardware it could only ever
produce a sparse point cloud — no mesh. The decision reverses only if dense work is
offloaded to an NVIDIA box.

The mesh stage is **Apple Object Capture** (`RealityKit.PhotogrammetrySession`),
GPU-accelerated on M-series and purpose-built for turntable capture. `objcap` is a
~130-line Swift CLI wrapping it, tuned with `sampleOrdering = .sequential`
(consecutive turntable frames overlap, so sequential matching is both correct and
faster) and `featureSensitivity = .high`.

Detail levels, measured on 144 images at 48 MP on an M4:

| Level | Time | Triangles |
|---|---|---|
| `reduced` | 6 m 20 s | 25 k |
| `full` | 6 m 52 s | 100 k |
| `raw` | 10 m 56 s | 212 k |

The useful finding: **`reduced` is only 32 seconds faster than `full`.** Around 90%
of runtime is ingesting and solving the images, which is identical across levels;
only the final mesh/texture stage differs. So `reduced` buys a *lighter file*, not a
faster run, and `raw` is the only level that adds real geometry.

## From mesh to printable solid

A single-ring turntable scan never photographs the object's underside, so the base
is fabricated — topologically closed by the Poisson surface, but geometrically
crude. `repair.py` turns the reconstruction into something a slicer will accept:
weld vertices → drop stray components → repair non-manifold edges and vertices →
close holes (watertight) → orient the flat face's normal to +Z by PCA → scale so the
widest in-plane extent is *N* mm (STL is unitless; slicers read mm) → Taubin-smooth
only the bottom band, leaving detailed geometry untouched → seat on Z=0.

**One ordering trap, learned the hard way:** close-holes fills *every* open boundary,
including see-through holes you meant to drill. Drill on an already-watertight solid,
never before the repair pass.

<p align="center">
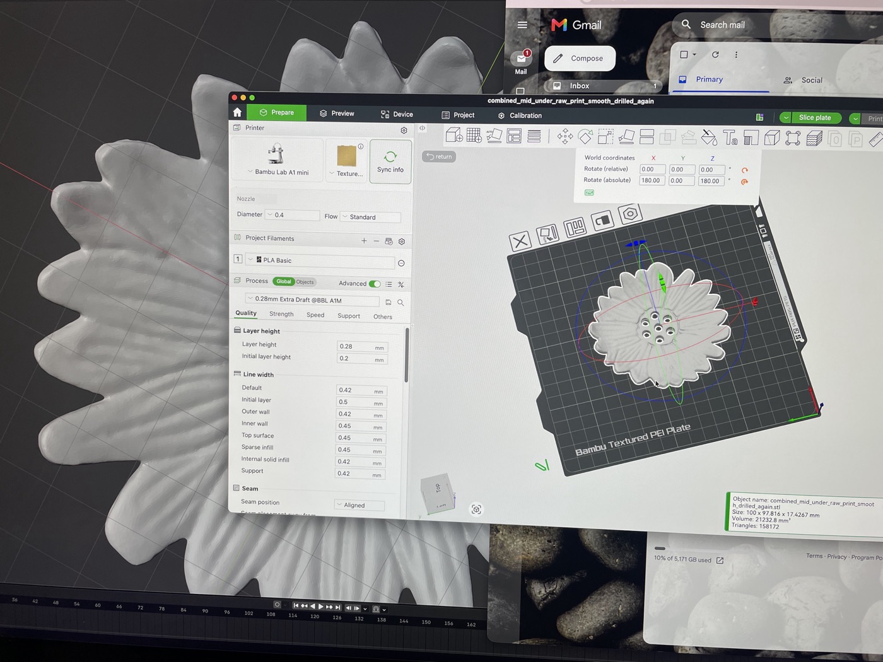
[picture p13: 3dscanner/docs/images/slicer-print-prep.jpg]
A slicer application showing the reconstructed flower mesh laid out on a print bed, with an info panel reading 100 x 97.816 x 17.4267 mm, volume 21232.8 cubic mm, 158172 triangles.
  
  <br>
  <em>The repaired mesh in the slicer, and the numbers are the point.
  <strong>100 × 97.816 × 17.4267 mm</strong> — <code>--diameter-mm 100</code> asked for a
  100 mm part and got one, which matters because STL carries no units and a slicer just
  reads the raw numbers as millimetres. The filename is the pipeline written out:
  <code>combined</code> mid + under rings, <code>raw</code> detail, base
  <code>smooth</code>ed, then <code>drilled</code>.</em>
</p>

<p align="center">
  The white ceramic daisy dish beside a dark grey 3D-printed copy of the same flower, both showing ridged petals and a ring of holes through the centre.
  <br>
  <em>Original and reproduction. The print carries the petal ridges and — the detail
  worth noticing — the <strong>ring of holes through the centre</strong>. Those are the
  drilled through-holes: cut as a boolean difference through an
  <em>already watertight</em> solid, because running the repair pass afterwards would
  have dutifully filled every one of them back in.</em>
</p>

## AI as an engineering harness

This project spans Swift, Python, Arduino C++, an HTTP protocol, photogrammetry, and
mesh tooling — five domains that would normally each carry their own ramp-up cost.
**Claude Code was used throughout** as an engineering agent: writing and debugging
across all of those boundaries, and compressing the integration work that usually
dominates a project like this.

What it did not do is decide when the thing actually worked. Every claim here was
settled physically — the IR emitter proved out by a turntable that visibly moved, the
capture chain by SHA-256 comparisons on real transfers, the reconstruction by meshes
that either registered or dropped frames, and the whole pipeline by a printed part
that either matched the original or did not.

The working principle: **use AI to cross domain boundaries quickly, but make physical
uncertainty explicit and validate every transition** — actuator to image, image to
mesh, mesh to manufactured part. The `UNKNOWN` turntable state, the five-stage hash
chain, and the `HEAD`-before-refire check are all that principle applied.

## State of the code

A working rig, honestly described. What that means:

- **The iOS app has no automated tests.** All 2,824 lines were verified by manual
  `curl` sequences against the physical device. The Python controller does have a
  suite — 25 tests, no mocking library, hand-rolled fakes injected through
  constructor seams, including one that spins a real HTTP server on a random port.
- **Bonjour advertisement is not implemented.** It is declared in `Info.plist`,
  required by the spec, and `/status` even *reports* a Bonjour name — but nothing
  ever sets `NWListener.service`. This is the likely root cause of a documented
  mystery in which `saru.local` never resolved and only the Tailscale address worked.
- **`project_id` is validated on the capture route but not on the `/projects/*`
  routes**, so an authenticated request can address a single-segment `..` and reach
  the data root. Auth-gated, but a real bug.
- **No log file.** `scan_log` is in the session layout, nothing writes it, and the
  package imports no logging module — operator feedback is `print()` only.
- **Calibration is a declared hook with no data behind it.** The config supports a
  per-step turntable calibration profile; none has been measured, so rotation runs
  on a nominal 13.3 °/s figure derived from timing one revolution.
- **Several config keys are parsed and never used** — `camera.fallback_url` most
  notably, which exists precisely to solve the mDNS problem above and is never tried.
- **`reconstruction.json` hardcodes `"device": "iPhone 12"`** although the rig has
  since moved to a different phone, so every packaged scan ships a wrong field.
- **The controller lock has a TOCTOU race** — an `exists()` check followed by a
  write, where `O_CREAT|O_EXCL` was called for.
- MVP constraints, by design: the angle step must divide evenly into 360, one
  camera ring per run, `tar.gz` the only package format.

## What actually makes a scan succeed

Rig and pipeline were solid from the first run; subject and scene choice turned out
to dominate results.

| Subject / scene | Frames used | Result |
|---|---|---|
| Glossy mug, cluttered desk with a **monitor** behind | — | hard failure |
| Glossy mug, light tent, matte backdrop | 10 / 36 | partial ~90° shell |
| Matte textured ceramic flower, light tent | 36 / 36 | clean full mesh |
| Same flower at 5° steps | 72 / 72 | clean; 87 k triangles at `full` |

| | |
|:--:|:--:|
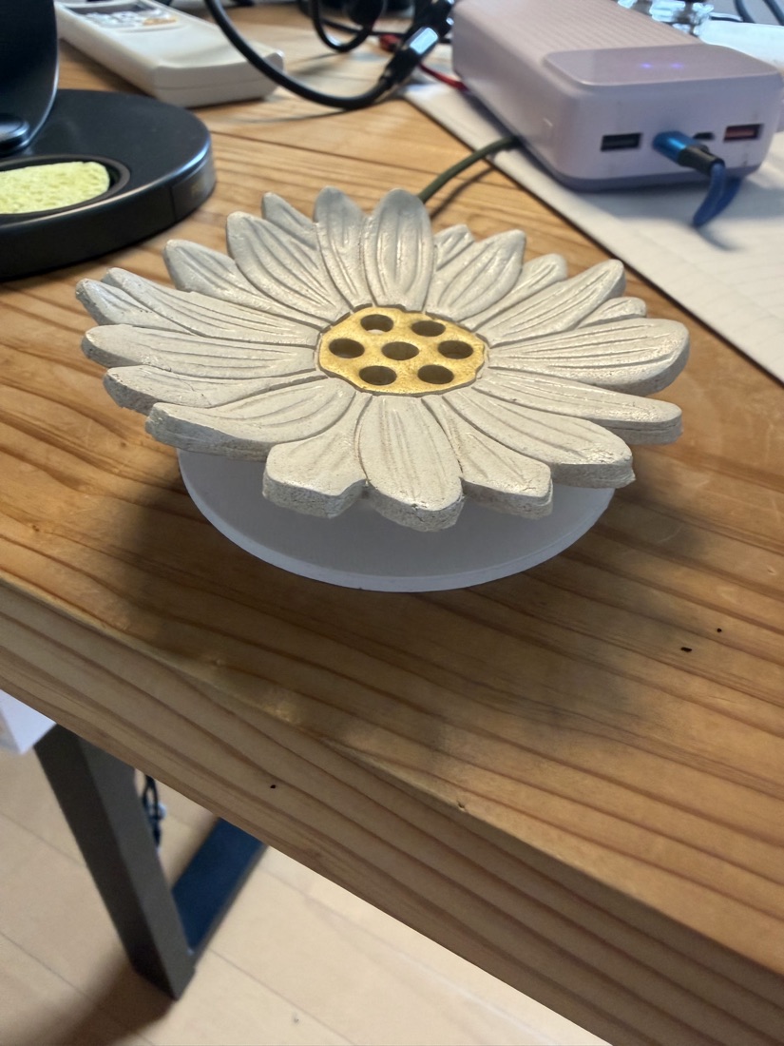
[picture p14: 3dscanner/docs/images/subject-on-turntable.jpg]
A white ceramic daisy dish with textured petals and a perforated yellow centre, sitting on the white turntable disc.
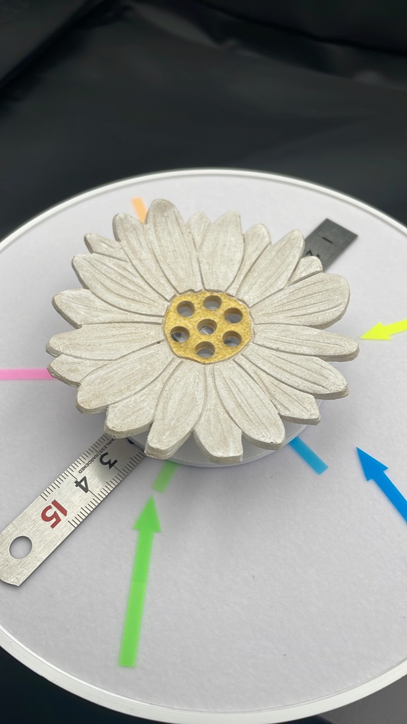
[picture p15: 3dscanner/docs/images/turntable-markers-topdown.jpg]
Top-down view of the daisy dish on the turntable disc, surrounded by coloured adhesive arrows and a steel rule laid on the disc surface.
|  |  |
| **A subject that reconstructs.** Matte, textured, asymmetric, opaque — every petal ridge is a feature the solver can lock onto, and the shape looks different from every angle. The glossy, rotationally symmetric mug that failed had neither property. | **Markers that rotate *with* the object.** The arrows and steel rule are taped to the disc, not the backdrop. That is the whole distinction: they move with the subject, so they stay consistent frame to frame and add trackable texture. The same markers on the background would break the solve. |

- A **feature-rich static background breaks the solve** — especially a monitor
  showing text. The object rotates and the background does not, and Object Capture
  cannot reconcile the two into one consistent scene. Anything sitting *on* the
  turntable is fine, because it rotates with the object.
- **Matte, textured, asymmetric** subjects register reliably. **Glossy and
  rotationally symmetric** ones drop frames past about 90°, because every angle looks
  alike and specular highlights slide across the surface instead of staying put.
- **A second camera elevation is worth more than more frames.** A mid ring plus a
  low "under" ring fused 128 of 144 frames — and the real gain was corrected
  *thickness*: the mid ring over-rounded an edge it could never see, and the under
  ring's edge-on views pinned the true thin profile.

## Key sources

Direct links into the code on GitHub:

| File | Why it's worth reading |
|---|---|
| [`turntable/base.py`](https://github.com/ariemeir/technical-portfolio/blob/main/3dscanner/capture/controller/turntable/base.py) | The assumed-state safety machine for an unobservable actuator |
| [`turntable/arduino_ir.py`](https://github.com/ariemeir/technical-portfolio/blob/main/3dscanner/capture/controller/turntable/arduino_ir.py) | Timed open-loop rotation; drops to `UNKNOWN` rather than guessing |
| [`controller/session.py`](https://github.com/ariemeir/technical-portfolio/blob/main/3dscanner/capture/controller/controller/session.py) | The scan loop — retry, idempotency, resumability, `HEAD`-before-refire |
| [`camera/scannercam.py`](https://github.com/ariemeir/technical-portfolio/blob/main/3dscanner/capture/controller/camera/scannercam.py) | Stdlib HTTP client; error classification and cursor pagination |
| [`tests/test_turntable.py`](https://github.com/ariemeir/technical-portfolio/blob/main/3dscanner/capture/controller/tests/test_turntable.py) | The safety machine pinned as behaviour, including both failure directions |
| [`Server/HTTPServer.swift`](https://github.com/ariemeir/technical-portfolio/blob/main/3dscanner/capture/iphone/ScannerCam/ScannerCam/Server/HTTPServer.swift) | Hand-rolled HTTP/1.1 on `NWListener`; per-connection queues and why |
| [`Camera/CameraController.swift`](https://github.com/ariemeir/technical-portfolio/blob/main/3dscanner/capture/iphone/ScannerCam/ScannerCam/Camera/CameraController.swift) | Focus/exposure/WB locking — the photogrammetry-critical surface |
| [`Server/Authentication.swift`](https://github.com/ariemeir/technical-portfolio/blob/main/3dscanner/capture/iphone/ScannerCam/ScannerCam/Server/Authentication.swift) | Constant-time token comparison, with a note not to "simplify" it |
| [`ir_blaster.ino`](https://github.com/ariemeir/technical-portfolio/blob/main/3dscanner/firmware/turntable_ir/ir_blaster.ino) | IR learn-and-transmit, including the Timer2 send/receive conflict |
| [`objcap/main.swift`](https://github.com/ariemeir/technical-portfolio/blob/main/3dscanner/reconstruction/objcap/Sources/objcap/main.swift) | RealityKit photogrammetry CLI and the OBJ-bundle URL workaround |
| [`scripts/repair.py`](https://github.com/ariemeir/technical-portfolio/blob/main/3dscanner/reconstruction/scripts/repair.py) | Mesh → printable solid: watertight, PCA-oriented, scaled to mm |
| [`docs/scannercam_spec.md`](https://github.com/ariemeir/technical-portfolio/blob/main/3dscanner/docs/scannercam_spec.md) | The full spec, with a section documenting what a review changed and why |

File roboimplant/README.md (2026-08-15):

# RoboImplant — Non-Invasive Adjustment System for a Spinal Distraction Implant

An orthopedic medical-device prototype: a motorized implant that lengthens a
spinal distraction rod without surgery, driven by an AVR controller and commanded
from an Android tablet over Bluetooth.

<p align="center">
  The assembled handheld driver unit: a 3D-printed orange enclosure with an acrylic top plate, gripped handle, and the lead screw and rod visible through the window.
  <br>
  <em><strong>v1</strong> — 3D-printed housing, acrylic top plate, brass inserts and
  drive coil. The clinician holds this against the patient over the implant site;
  the drive coil couples magnetically through tissue to the implant's internal
  mechanism.</em>
</p>

Built ~2012–2013. Author: Arie Meir. Institutional work — see [NOTICE.md](NOTICE.md).

**→ [Read the one-page case study (PDF)](docs/roboimplant-case-study-arie-meir.pdf)**
· [Browse the source on GitHub](https://github.com/ariemeir/technical-portfolio/tree/main/roboimplant)

> **Reference only.** Not a cleared or approved medical device. Not for clinical
> use. All sample patient data in this repository is fictitious.

---

## The problem

Early-onset scoliosis is treated with growing rods implanted along the spine.
As the child grows, the rods must be lengthened — historically through a repeat
surgery every six months or so, each one carrying anesthetic and infection risk
and accumulating scar tissue.

This system lengthens the rod **without opening the patient**. An external driver
unit is placed against the skin over the implant, couples to it, and rotates an
internal lead screw. A clinician runs the procedure from a tablet, watching live
telemetry, and stops the moment anything looks wrong.

## How it works

```
┌─────────────────┐   Bluetooth SPP    ┌──────────────────┐   analog set-value  ┌─────────────┐
│  Android tablet │◄──────────────────►│   ATmega1284P    │────────────────────►│ maxon ESCON │
│   (clinician)   │  ASCII "at…"/"bt…" │   controller     │   via DS1267 pot    │  36/2 DC    │
└─────────────────┘                    └──────────────────┘                     └──────┬──────┘
                                          ▲   ▲                                        │
                              current /   │   │  rotation count                        ▼
                              voltage ADC │   │  (INT2, rising edge)              DC motor
                                          │   └────────────────────────────────────────┤
                                          └────────────────────────────────────────────┘
                                                                                   ┌────▼────┐
                                                                                   │ implant │
                                                                                   │   rod   │
                                                                                   └─────────┘
```

The clinician enters a **dose** — the console works in micrometres, typically
**20 µm per increment**, with cumulative elongation displayed in millimetres. The
controller converts the dose to a target number of motor rotations, spins the
motor, counts rotations via an interrupt, and stops when the target is reached.

Available drive torque falls off as the distance between actuator and implant
grows, which is why the system carries dedicated calibration routines for both
coupling and extension behaviour.

**Coupling detection is the safety-critical part.** The driver is only actually
turning the implant when it is mechanically engaged with it. Engagement shows up
as a step change in motor current — an uncoupled motor spins nearly free. The
firmware thresholds motor current at `COUPLING_THRESHOLD_CURRENT` (35 mA) to
decide whether it is coupled, and reports every transition to the tablet
immediately rather than waiting for the next periodic update. If coupling is
lost mid-procedure, rotation counting stops, so a rod that isn't turning is never
credited with lengthening it didn't do.

<p align="center">
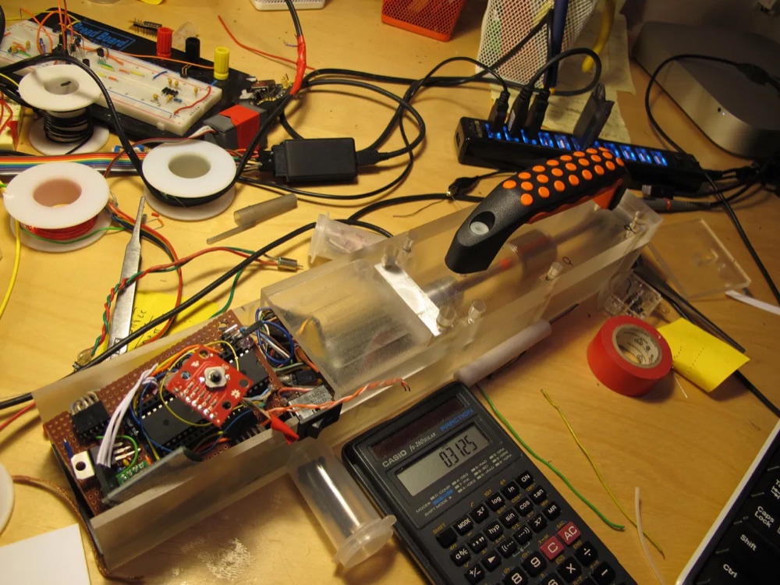
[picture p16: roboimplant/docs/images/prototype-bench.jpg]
The driver unit opened up on a workbench, showing hand-soldered perfboard with the ATmega microcontroller, wiring, and the motor and lead screw inside a clear acrylic housing.
  
  <br>
  <em><strong>v2</strong> — machined polycarbonate body with the controller
  electronics integrated alongside the coil assembly, shown open on the bench.</em>
</p>

## The clinician console

The Android app is what the clinician actually operates. Four screens carry the
whole workflow:

| | |
|:--:|:--:|
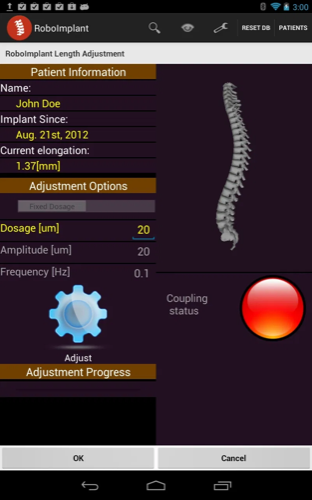
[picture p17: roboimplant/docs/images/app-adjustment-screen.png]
Procedure screen showing patient information, dosage entry, a 3D spine render, and a red coupling status indicator.
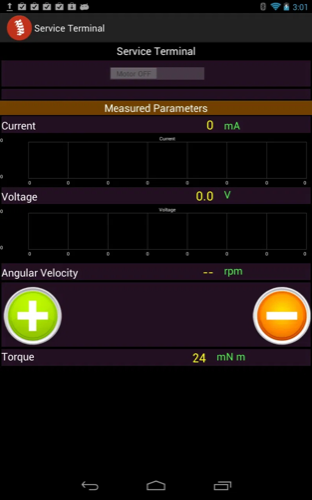
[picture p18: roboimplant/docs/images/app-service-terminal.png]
Service terminal screen with live current and voltage plots, angular velocity, and torque readouts.
|  |  |
| **Procedure screen.** Dosage entry, current elongation, and the coupling indicator — red until motor current crosses 35 mA, which is how the system knows the driver is genuinely engaged with the implant rather than spinning free. | **Service terminal.** The engineering view: current, voltage, angular velocity, and torque derived from the motor constants, plotted live from the `bt*` telemetry stream. |
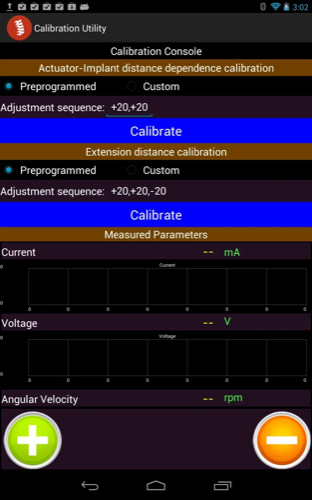
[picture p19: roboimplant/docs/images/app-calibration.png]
Calibration console with preprogrammed and custom adjustment sequences and live measurement plots.
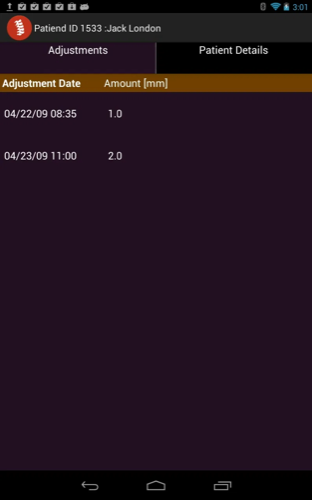
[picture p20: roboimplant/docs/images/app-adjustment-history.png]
Per-patient adjustment history listing dates and lengthening amounts in millimetres.
|  |  |
| **Calibration.** Runs preprogrammed adjustment sequences to characterise actuator-to-implant distance dependence and extension distance, capturing the no-load and loaded currents that set the coupling threshold. | **Adjustment history.** Per-patient log of every adjustment, with date and lengthening in millimetres. All sample data shown is fictitious. |

The 3D spine in the first screenshot was rendered with min3d from the mesh that
has since been removed for provenance reasons — see [NOTICE.md](NOTICE.md).

## Repository layout

| Path | Contents |
|---|---|
| [`firmware/`](firmware/) | AVR C firmware for the ATmega1284P controller |
| [`android/`](android/) | Eclipse ADT project — the clinician console app |
| [`hardware/`](hardware/) | EAGLE 6.1 schematic and board layout (`pcb/`), plus SolidWorks parts and assembly for the handheld driver (`enclosure/`) |
| [`models/`](models/) | 3D rod models used by the app's visualization |
| [`docs/motor/`](docs/motor/) | maxon ESCON 36/2 servo-controller reference (vendor docs) |

## Serial protocol

Plain ASCII over Bluetooth SPP, line-oriented. Symmetric halves live in
`firmware/messageDispatcher.c` and
`android/src/edu/ucsf/roboimplantconsole/MessageDispatcher.java`.

**Tablet → controller** — `at`-prefixed, terminated `\n\r`:

| Command | Effect |
|---|---|
| `atmotoron` / `atmotoroff` | Enable / disable the motor |
| `atspeed <n>` | Set speed (0–255, digital-pot step) |
| `atcw` / `atccw` | Set rotation direction |
| `atdosage <n>` | Set target lengthening |
| `atstart` / `atstop` | Begin / end a procedure |
| `atreset` | Reset counters and statistics |
| `atupdate <0\|1>` | Toggle periodic telemetry |
| `atupdateinterval <ms>` | Set telemetry period (default 2500 ms) |
| `ati` / `atr` / `atu` / `atblink` | Info, read, unit, and LED-blink diagnostics |

Replies are `OK` or `ERROR`.

**Controller → tablet** — `bt`-prefixed telemetry:

`btcurrent` · `btcurrentamplitude` · `btvoltage` · `btvoltageamplitude` ·
`btangularspeed` · `btmseccounter` · `btremaining` · `btterminated` ·
`btlostcoupling` · `btestablishedcoupling`

The AVR has no floating-point unit worth using over a serial link, so numeric
values are transmitted as integers alongside their scaling factor — each numeric
opcode carries `<scaledValue> <scalingFactor>`, with the factor fixed at 1000
(`SCALING_FACTOR` in `firmware/config.h`). The Android side divides on receipt.

## State of the code

This is an archival snapshot of a research prototype, published as-is. Being
straight about what that means:

- **The Android project does not build as shipped.** Its Eclipse `.classpath` and
  `.project` reference two dependencies by absolute path on the original
  developer's Linux machine (`/home/ariemeir/…`): the **min3d** 3D engine, linked
  as a source folder, and **achartengine-1.0.0.jar**. Neither is included here.
  See [`android/README.md`](android/README.md).
- **Several firmware modules are present but not compiled.** The `SRC` line in
  `firmware/Makefile` excludes the SD-card logging subsystem, the AD7715 external
  ADC, and `samples.c`. These are experimental paths kept for reference.
  `lcd.c` is 8051/Keil code that would not compile against AVR at all.
- **Hardware artifacts are in proprietary binary formats.** The schematic needs
  EAGLE 6.x; the enclosure needs SolidWorks. No neutral STEP/STL/PDF exports were
  made, so neither is viewable directly on GitHub.
- The Android manifest requests several permissions the app does not need
  (`ACCESS_SURFACE_FLINGER`, `ACCESS_FINE_LOCATION`, `READ_PHONE_STATE`, and
  `ACCESS_BACKGROUND_SERVICE`, which is not a real Android permission). Vestigial.
- `ConfigDB.java` hardcodes the Bluetooth MAC addresses of the original bench
  hardware.
- **The anatomical spine mesh has been removed** because its origin could not be
  verified, so the app's 3D spine view has no geometry to load. Rod geometry is
  original and retained. See [NOTICE.md](NOTICE.md).

## Key sources

Direct links into the code on GitHub:

| File | Why it's worth reading |
|---|---|
| [`firmware/config.h`](https://github.com/ariemeir/technical-portfolio/blob/main/roboimplant/firmware/config.h) | System model — every physical parameter, calibration value, and state struct in one place |
| [`firmware/main.c`](https://github.com/ariemeir/technical-portfolio/blob/main/roboimplant/firmware/main.c) | Timer/interrupt setup, procedure state machine, coupling logic |
| [`firmware/messageDispatcher.c`](https://github.com/ariemeir/technical-portfolio/blob/main/roboimplant/firmware/messageDispatcher.c) | Command parser, controller side |
| [`firmware/digitalPot.c`](https://github.com/ariemeir/technical-portfolio/blob/main/roboimplant/firmware/digitalPot.c) | DS1267 SPI driver — how motor speed is actually commanded |
| [`firmware/adc.c`](https://github.com/ariemeir/technical-portfolio/blob/main/roboimplant/firmware/adc.c) | Current/voltage sensing — the input to coupling detection |
| [`AdjustmentActivity.java`](https://github.com/ariemeir/technical-portfolio/blob/main/roboimplant/android/src/edu/ucsf/roboimplantconsole/AdjustmentActivity.java) | The procedure screen the clinician drives |
| [`MessageDispatcher.java`](https://github.com/ariemeir/technical-portfolio/blob/main/roboimplant/android/src/edu/ucsf/roboimplantconsole/MessageDispatcher.java) | Telemetry parser and listener fan-out |
| [`BluetoothSerialService.java`](https://github.com/ariemeir/technical-portfolio/blob/main/roboimplant/android/src/edu/ucsf/roboimplantconsole/bluetooth/BluetoothSerialService.java) | Bluetooth SPP connection state machine |

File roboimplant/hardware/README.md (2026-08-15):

# Hardware

**→ [Browse this directory on GitHub](https://github.com/ariemeir/technical-portfolio/tree/main/roboimplant/hardware)**
· [`pcb/`](https://github.com/ariemeir/technical-portfolio/tree/main/roboimplant/hardware/pcb)
· [`enclosure/`](https://github.com/ariemeir/technical-portfolio/tree/main/roboimplant/hardware/enclosure)

| | |
|:--:|:--:|
| Assembled driver unit in a 3D-printed orange enclosure with acrylic top plate and gripped handle. | Driver unit opened on a workbench showing hand-soldered perfboard, the ATmega, motor and lead screw. |
| **v1** — 3D-printed housing, acrylic top plate, brass inserts and drive coil. | **v2** — machined polycarbonate body with the controller electronics integrated alongside the coil assembly. |

The SolidWorks files below model the v1 unit on the left.

## `pcb/` — controller board

EAGLE 6.1 (CadSoft) design files for the board carrying the ATmega1284P, the
DS1267 digital potentiometer, the current/voltage sensing chain, the Bluetooth
module, and power management.

| File | |
|---|---|
| `roboimplantschematic.sch` | Schematic |
| `roboimplantschematic.brd` | Board layout |

**Viewing requires EAGLE 6.x or later** (now Autodesk EAGLE / Fusion Electronics).
Both files are EAGLE's XML format. No PDF export, gerbers, drill files, or BOM
were produced, so the design is not viewable or manufacturable directly from this
repository — exporting a schematic PDF would be the single highest-value addition.

## `enclosure/` — handheld driver housing

SolidWorks parts and assembly for the housing the clinician holds against the
patient.

| File | |
|---|---|
| `new_controller_enclosure_assembly.SLDASM` | Top-level assembly |
| `enclosure_bottom.SLDPRT` | Main body |
| `enclosure_circuit_cover.SLDPRT` | Electronics compartment cover |
| `enclosure_battery_cover.SLDPRT` | Battery compartment cover |
| `motor_top_cover.SLDDRW.SLDPRT` | Motor cover |
| `pcb.SLDPRT` | Board model, for fit-checking |
| `6mm_rod.SLDPRT` | Rod model |

**Requires SolidWorks.** No STEP, IGES, STL, or DXF exports were made.

Two known quirks, left as-found rather than tidied:

- `motor_top_cover.SLDDRW.SLDPRT` has a doubled extension from a save-as
  accident. It is a **part** file, not a drawing, and opens correctly as one —
  no `.SLDDRW` was ever preserved.
- The assembly stores references to its component files by name. If parts are
  renamed or moved, SolidWorks will report broken references and need them
  re-pointed.

## Motor controller

The board drives a **maxon ESCON 36/2 DC** servo controller (P/N 403112) via an
analog set-value input. Vendor documentation is in [`../docs/motor/`](../docs/motor/);
motor constants used by the firmware are in `firmware/config.h`.

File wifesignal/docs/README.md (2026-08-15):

# Documentation

| Path | Contents |
|---|---|
| [`wifesignal-case-study-arie-meir.pdf`](wifesignal-case-study-arie-meir.pdf) | One-page case study — the project at a glance. |
| [`images/`](images/) | Original photographs of the device and its construction, plus one screenshot of the project's own iOS app. |

The full case study is the [project README](../README.md).

## Images

| File | Subject |
|---|---|
| `signal-lit-green-on-desk.jpg` | The finished device in service, showing green |
| `app-signal-screen.png` | The iOS app's single screen |
| `prototype-protoboard.jpg` | Stage 1 — one channel on protoboard |
| `pcb-rev-a-bare.jpg` | Stage 2 — the fabricated Rev A board, unpopulated |
| `assembly-buttons-wired.jpg` | Stage 3 — board wired to the three arcade buttons |
| `pcb-in-enclosure-tray.jpg` | Stage 4 — the board seated on the enclosure pillars |

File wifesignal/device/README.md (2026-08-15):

# Device — PCB and Enclosure

The physical object: a custom two-layer PCB carrying three lamp-driver channels, an
ESP32-C3 on removable headers, and three 30 mm illuminated arcade buttons in a
3D-printed two-part enclosure.

**→ [Browse this directory on GitHub](https://github.com/ariemeir/technical-portfolio/tree/main/wifesignal/device)**

| | |
|:--:|:--:|
| A bare green printed circuit board, rounded at one end and square at the other, with four semicircular notches cut into its long edges. White silkscreen marks three transistor outlines Q1 to Q3, three resistor footprints R1 to R3, and two eight-pin headers J1 and J2. | The green circuit board resting inside a grey 3D-printed tray, supported on four dark hexagonal pillars that pass through the notches in the board's edges. |
| **Rev A, as fabricated.** Entirely through-hole, two layers, 62 track segments, no vias. The rounded end and the four edge notches are dictated by the enclosure. | **Mechanical fit.** The board drops over four M4 pillars. The notch centres at (±16, ±18.5) mm are cut to clear them exactly. |

## The circuit

Three identical channels, each a textbook low-side switch:

```
GPIO ──[1k]── base ; emitter ── GND ; collector ── lamp cathode
                                      lamp anode ── +5V
```

| Ref | Part | Notes |
|---|---|---|
| J1, J2 | 1×8 pin headers | ESP32-C3 SuperMini Plus, on **female** headers so the module is removable |
| J3, J4, J5 | 1×4 pin headers | One per button: `LED+`, `LED−`, switch `COM`, switch `NO` |
| Q1, Q2, Q3 | S8050 NPN *on the schematic* | **S8550 PNP as actually soldered** — see below |
| R1, R2, R3 | 1 kΩ | Base resistors |

Channel mapping carries through to the silkscreen: `R1/Q1/J3` = red, `R2/Q2/J4` =
yellow, `R3/Q3/J5` = green. Power arrives from the ESP32's USB connector, so three
`PWR_FLAG`s assert the +5 V and GND nets for the electrical rules check.

## ⚠️ The schematic is knowingly wrong

The board was populated with **S8550 PNP** transistors from an assortment kit; the
schematic specifies **S8050 NPN**. The part numbers differ by one character. This
was discovered only when the lamps behaved backwards.

A PNP low-side driver inverts the control sense — **GPIO LOW turns the lamp on** —
and the fix lives in the firmware rather than in a rework, because reworking three
transistors on an otherwise working board buys nothing but agreement with a drawing.
The schematic is left as-is and documented as wrong in three places, including a
shouted comment in the firmware header telling the next engineer not to "fix" it.

## Board geometry

41.0 × 88.5 mm. Flat at one end, a R20.5 semicircular arc at the other. Four
C-shaped notches (R4.7) centred at (±16, ±18.5) mm from the board centre.

The notches are the interesting part: the electrical and mechanical designs are
**dimensionally coupled**, and both say so in comments. The enclosure generator
places its four M4 pillars at exactly those coordinates, and the board is cut to
drop over them. Change one and the other stops fitting.

## Directories

| Path | Contents |
|---|---|
| [`WifeSignalPCB/`](WifeSignalPCB/) | KiCad project. `WifeSignal3ch.*` is the board that was fabricated; `WifeSignal.*` is an unrouted 1-channel variant kept as design history. `output/` holds the gerbers and drill files sent for fabrication. |
| [`enclosure/`](enclosure/) | The Fusion 360 script that generates the enclosure — the CAD source of truth. |

## Bill of materials

| Qty | Item |
|---|---|
| 1 | ESP32-C3 SuperMini Plus |
| 3 | 30 mm illuminated arcade buttons (red, yellow, green), 4-terminal |
| 3 | S8550 PNP transistors, TO-92 |
| 3 | 1 kΩ resistors, axial |
| 2 | 1×8 female pin headers |
| 3 | 1×4 pin headers |
| 4 | M4 × 10 bolts + nuts (press-fit into the printed pillars) |
| 1 | Custom PCB, 41.0 × 88.5 mm, two layers, through-hole |

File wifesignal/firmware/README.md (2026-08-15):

# Firmware — ESP32-C3 BLE Peripheral

A BLE peripheral exposing one service with one characteristic carrying one byte.
134 lines. It drives three illuminated arcade buttons and reports physical presses
back to the server.

**→ [Browse this directory on GitHub](https://github.com/ariemeir/technical-portfolio/tree/main/wifesignal/firmware)**

| | |
|---|---|
| Board | ESP32-C3 SuperMini Plus (`ESP32C3 Dev Module`, USB CDC On Boot = Enabled) |
| BLE stack | NimBLE-Arduino v2.x |
| Service UUID | `6d5f0001-4b6b-4a3a-9e1e-2a7b1c9f0001` |
| STATE characteristic | `6d5f0002-4b6b-4a3a-9e1e-2a7b1c9f0002` — `READ` \| `WRITE` \| `NOTIFY`, 1 byte |
| State byte | `0` all off, `1` red, `2` yellow, `3` green |

## Pins as built

| | Red | Yellow | Green |
|---|---|---|---|
| **switch** (`INPUT_PULLUP`, press = LOW, COM → GND) | GPIO3 | GPIO4 | GPIO5 |
| **lamp** (via 1 kΩ into a transistor base) | GPIO6 | GPIO7 | GPIO10 |

Plus the onboard LED on GPIO8 (inverted, LOW = ON) mirroring `state != 0`.

**GPIO 2, 8 and 9 are strapping pins; 20 and 21 are UART0.** All five are avoided
for channel use. Strapping pins are sampled at reset to select boot mode — hanging
a lamp driver off one yields a board that works perfectly until the day it refuses
to start.

## ⚠️ Lamp polarity is inverted on purpose

The soldered drivers are **S8550 PNP**. The schematic says **S8050 NPN** — an
assortment-kit mixup found after the board was populated. The parts on the board
win:

```c
digitalWrite(LAMP[i], (state == i + 1) ? LOW : HIGH);   // PNP: LOW = ON
```

**Do not "correct" this to NPN logic.** Reworking three transistors on a working
board buys nothing but agreement with a drawing.

### The boot-flash fix

A pin that has not yet been configured as an output floats, and a floating base on
a PNP low-side driver reads as *on* — so every boot flashed all three lamps. The
fix is an ordering trick worth remembering:

```c
digitalWrite(LAMP[i], HIGH);   // latch the level into the output register first
pinMode(LAMP[i], OUTPUT);      // then enable the driver
digitalWrite(LAMP[i], HIGH);   // and assert it again
```

Writing before `pinMode` sets the output register while the pin is still an input,
so the pin never passes through an undefined state on its way to being driven.

## Button semantics

These must stay in lockstep with the server's notify classifier:

| Condition | Result |
|---|---|
| press any button while `state != 0` | `state = 0` + notify — **this is the acknowledgement** |
| press a button while `state == 0` | `state` = that button's colour; the server writes it back off (reserved "ping back" hook) |

Debounce is 40 ms with a per-button `handled` flag, so holding a button produces one
event rather than a stream.

## Files

| File | Status |
|---|---|
| [`wifesignal_3ch/wifesignal_3ch.ino`](wifesignal_3ch/wifesignal_3ch.ino) | **Production.** The 3-channel firmware running on the Rev A board. |
| [`wifesignal_bletest.ino`](wifesignal_bletest.ino) | **Bring-up, superseded.** The 1-channel sketch that proved the BLE service, the button semantics and the inverted polarity before the PCB existed. Same UUIDs, a boolean state, one button on GPIO3 and one lamp on GPIO6. Kept as design history — it is a *different pins and polarity era* and should not be flashed to the current board. |

## Building and flashing

```bash
arduino-cli compile --fqbn esp32:esp32:esp32c3:CDCOnBoot=cdc wifesignal_3ch
```

The board enumerates as `/dev/cu.usbmodem*` over native USB CDC. Two practical
notes, both learned the hard way:

- **Close any serial monitor first.** The port is exclusive, and a stale
  `arduino-cli monitor` produces a "port busy" upload failure that does not name the
  culprit. `lsof /dev/cu.usbmodem*` finds it.
- **Positively identify the board before flashing** if other ESP32 projects share
  the machine. This firmware prints `write -> state N` at 115200 when toggled
  through the API, which is an unambiguous test.

The server reconnects by itself after a flash, and re-asserts the correct lamp state
on connect — so reflashing mid-signal is safe.

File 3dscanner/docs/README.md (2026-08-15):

# Documentation

| Document | What it is |
|---|---|
| [`3dscanner-case-study-arie-meir.pdf`](3dscanner-case-study-arie-meir.pdf) | One-page case study — the problem, the pipeline, the engineering principles |
| [`scannercam_spec.md`](scannercam_spec.md) | The ScannerCam technical specification — 1,731 lines, v0.2 |
| [`engineering-log.md`](engineering-log.md) | Decisions, bugs with root causes, and measured results |

## The spec

Written before the iPhone app, and followed. It covers the project and file model,
capture lifecycle, network and authentication model, all thirteen endpoints with
request/response shapes, concurrency and data-integrity requirements, storage
protection, acceptance criteria, and an explicit out-of-scope list.

Its final section, **Revision notes (v0.1 → v0.2)**, is the part worth reading first.
It records what a technical review of the original draft changed and why — including
the filename scheme that broke on overwrite, an underspecified HTTP scope that would
have hung clients on keep-alive, an unaddressed delete-versus-download race, and four
acceptance criteria that the original twenty never exercised.

Deployment specifics in §0 (signing team, device identifiers, network addresses) have
been replaced with placeholders for publication — see [`../NOTICE.md`](../NOTICE.md).

## The engineering log

Adapted from the project's working handoff document. It keeps the reasoning rather
than just the outcomes: why COLMAP was evaluated and removed, why a capture blocks
its own request thread, what actually caused the server to wedge, why infrared
transmitted but nothing decoded it, and which subjects reconstruct cleanly versus
which quietly fail.

It ends with corrections to claims the original notes made confidently and got wrong.

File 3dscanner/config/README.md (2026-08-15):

# Configuration

[`scanner.example.yaml`](scanner.example.yaml) is the template. Copy it to
`scanner.yaml` — which is excluded from version control, because it identifies
specific hardware and a specific network — and fill in the real values.

```bash
cp config/scanner.example.yaml config/scanner.yaml
```

The API token is **never** stored in either file. The config names an environment
variable (`token_env`, default `SCANNERCAM_TOKEN`) and the controller reads the token
from there at runtime, failing with a pointer to the app's Settings screen if it is
missing.

## Groups

| Group | Controls |
|---|---|
| `camera` | Phone base URL, timeouts, and `require_locks` — whether a scan may proceed with focus/exposure/white balance unlocked |
| `turntable` | Driver (`arduino_ir` or `noop`), serial port, and the paths to the firmware directory that owns the IR codes |
| `turntable.movement` | The timing model — see below |
| `capture` | Degrees per frame, settle times, retry counts, whether to verify SHA-256 |
| `session` | Directory roots for in-progress, completed, and failed scans; package format |

## The timing model

Rotation is open loop. There is no encoder and no feedback, so a step is a timed
pulse:

```
run_seconds = degrees / degrees_per_second
            − toggle_command_latency_seconds
            − stop_coast_seconds
```

floored at `minimum_run_seconds`.

`degrees_per_second` is measured by timing one full revolution at the speed the table
will actually run at — 13.3 °/s in the reference setup, from a 27-second revolution
at the slowest setting. The latency and coast terms compensate for the round trip to
the Arduino and the motor's deceleration after the stop toggle.

This is approximate by construction. The seam will not land exactly at 360°, and that
is fine: the reconstruction stage recovers true camera pose from image features, so
nominal angles only need to be even enough to give good coverage.

An optional calibration profile at `calibration/turntable/default.yaml` can override
`degrees_per_second` and the latency/coast terms, or supply exact per-step
`run_seconds` values that win outright. **The hook is implemented; no profile has
been measured**, so the nominal figure is what runs.

`degrees_per_frame` must divide evenly into 360.

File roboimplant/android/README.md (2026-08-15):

# Android Console

The clinician-facing tablet app. Connects to the controller over Bluetooth SPP,
runs a lengthening procedure, and displays live telemetry against a 3D render of
the spine and rod.

Eclipse ADT project, package `edu.ucsf.roboimplantconsole`, circa 2012–2013.

**→ [Browse this directory on GitHub](https://github.com/ariemeir/technical-portfolio/tree/main/roboimplant/android)**
· [`src/`](https://github.com/ariemeir/technical-portfolio/tree/main/roboimplant/android/src/edu/ucsf)

| | | | |
|:--:|:--:|:--:|:--:|
| Procedure screen with dosage entry, 3D spine render, and coupling indicator. | Service terminal with live current and voltage plots. | Calibration console with adjustment sequences. | Per-patient adjustment history. |
| `AdjustmentActivity` | `ServiceTerminal` | `CalibrationActivity` | `AdjustmentListActivity` |

Running on a Nexus 7 under Android 4.x. Sample patient data is fictitious.

| | |
|---|---|
| minSdkVersion | 14 (Android 4.0) |
| targetSdkVersion | 15 |
| Compile target | `Google Inc.:Google APIs:16` |
| Transport | Bluetooth RFCOMM/SPP, UUID `00001101-0000-1000-8000-00805F9B34FB` |

## ⚠️ Does not build as shipped

Two dependencies are referenced by **absolute path on the original developer's
machine** and are not included in this repository:

```
.classpath  →  /home/ariemeir/unison-root/dev/android/achartengine/achartengine-1.0.0.jar
.project    →  /home/ariemeir/dev/min3d/src   (linked source folder "min3d")
```

- **min3d** — OpenGL ES 3D engine, used for the spine/rod visualization. MIT.
- **AChartEngine 1.0.0** — charting. Apache-2.0.

Building requires obtaining both and fixing the paths. The project also targets
the **Google APIs add-on** for API 16, not the plain `android-16` platform, so
`project.properties` needs editing to build against a stock SDK. Preserved
unmodified as a historical snapshot rather than retrofitted to Gradle.

## Structure

Two package trees, reflecting two development phases:

**`edu.ucsf.roboimplantconsole`** — device communication and the procedure itself.

| Class | Role |
|---|---|
| `AdjustmentActivity` | Launcher. The procedure screen — dosage entry, live telemetry, 3D view |
| `MessageDispatcher` | Parses `bt*` telemetry, fans out to `RoboMessageListener`s and static UI hooks |
| `CalibrationActivity` | Captures no-load / loaded current and speed calibration points |
| `ServiceTerminal` | Engineering view — raw terminal and graphs |
| `RoboImplantPreferences` | Settings |
| `SoundNotifier` | Audio cues for procedure events |
| `bluetooth/BluetoothSerialService` | Connection state machine (AOSP-derived) |
| `bluetooth/DeviceListActivity` | Device picker |
| `bluetooth/BlueTerm` | Singleton terminal-services wrapper — see [`../NOTICE.md`](../NOTICE.md) |

**`edu.ucsf.roboimplant`** — patient records and UI scaffolding.
`menu/` (patient and adjustment lists, tabs), `ui/` (patient and adjustment
screens), `db/` (SQLite adapters), `data/`, `generic/`, `calib/`.

## Notes on the code

- **All sample patient data is fictitious** — `db/DatabaseHelper.java` seeds
  "Jack London" and "Steve Jordan" with invented Bay Area addresses and phone
  numbers. No real patient data has ever been in this repository.
- **`db/DBSimulator.java` is vestigial.** It loads `_so.csv`, `_labor.csv`, and
  `_parts.csv` — service orders, labor, and parts — from `/sdcard/roboimplant/`.
  That is the data model of a field-service application this project borrowed
  scaffolding from, unrelated to the implant domain. No CSVs ship here. Kept
  because it is part of the honest history of the codebase.
- **Over-broad permissions.** The manifest requests `ACCESS_SURFACE_FLINGER`
  (signature-level, never granted to a normal app), `ACCESS_FINE_LOCATION`,
  `READ_PHONE_STATE`, `INTERNET`, and `ACCESS_BACKGROUND_SERVICE` — which is not
  a real Android permission. Only `BLUETOOTH`, `BLUETOOTH_ADMIN`, and `VIBRATE`
  are actually needed. Vestigial, and would not survive review today.
- **`generic/ConfigDB.java` hardcodes bench-hardware Bluetooth MACs**
  (`CAMERA_CLICKER_ADDRESS`, `MOTOR_CONTROLLER_ADDRESS`).
- `bin/` and `gen/` (build output, including a compiled APK) are excluded via
  `.gitignore`.
- **The spine meshes in `res/raw/` were removed** (`spine_obj`, `spine_lowres_obj`)
  because their provenance could not be verified — the 3D view has no spine
  geometry to load. `rod_obj` is original and retained. See [`../NOTICE.md`](../NOTICE.md).

See [`../README.md`](../README.md) for the serial protocol both sides implement.

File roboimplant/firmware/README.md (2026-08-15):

# Firmware — ATmega1284P Controller

AVR C firmware for the handheld driver unit. Parses commands from the Android
console over Bluetooth serial, drives the maxon ESCON servo controller, counts
rod rotations, and streams telemetry back.

**→ [Browse this directory on GitHub](https://github.com/ariemeir/technical-portfolio/tree/main/roboimplant/firmware)**

## Target

| | |
|---|---|
| MCU | ATmega1284P |
| Clock | 16 MHz |
| Toolchain | avr-gcc / WinAVR-style Makefile |
| Programmer | `avrispv2` on `/dev/ttyACM0` |
| Serial | 57600 baud |

## Build

```sh
make          # build main.elf / main.hex
make program  # flash via avrdude
```

Requires the AVR toolchain (`avr-gcc`, `avr-libc`, `avrdude`).

## Design

**Time base.** Timer2 in CTC mode, `OCR2A = 250`, prescaler 64 → an interrupt
every 1.024 ms at 16 MHz. This is the millisecond clock for the whole system
(`TIME_COUNTS_IN_ONE_SEC`). The 2.4% error is acknowledged in a comment in
`config.h` — an external 32 kHz crystal was the intended fix.

**Speed control.** Motor speed is *not* set by the AVR's PWM in the shipped
signal path. A **DS1267 digital potentiometer** on SPI (`digitalPot.c`) feeds the
analog set-value input of the ESCON controller; `HALTING_SPEED_VALUE` (110) is
the pot step corresponding to zero speed. A hardware PWM on Timer0/OC0A (`pwm.c`)
exists alongside it and is reachable via `atpwm`.

**Rotation counting.** External interrupt INT2 on the rising edge increments
`spinCount`. Procedure targets are expressed in spin counts, derived from the
requested millimetres via `MM_TO_ROTATIONS_FACTOR`.

**Sensing.** `adc.c` reads motor current and voltage through a conditioning chain
centred at Vcc/2. Motor constants (`TORQUE_CONSTANT` 23.5 mNm/A, `SPEED_CONSTANT`
406 rpm/V) come from the maxon datasheet and let torque and speed be inferred
from current and voltage without extra sensors. Samples feed a cumulative moving
average (`HISTORY_AVG_WEIGHT`, `AVG_HISTORY_LENGTH`).

**Coupling detection.** Motor current is thresholded at
`COUPLING_THRESHOLD_CURRENT` (35 mA) to decide whether the driver is engaged with
the implant. Transitions are pushed to the console immediately via
`notifyCoupling()` rather than waiting for the next periodic update, because
losing coupling mid-procedure has to surface to the clinician at once.

**I/O.** Dual UART — stdout to the Bluetooth module on UART1, stderr to RS-232 on
UART0, switchable with `USE_RS232_UART`. A Parallax 5-way joystick
(`parallax5buttonjoystick`) provides local control without the tablet.

## What is and isn't built

The `SRC` line in the Makefile compiles:

```
main.c uart.c adc.c spi.c messageDispatcher.c utils.c
pwm.c printFloat.c power.c calibration.c digitalPot.c parallax5waybutton.c
```

Present but **excluded from the build**:

- **`sdcard/`** — SD/FAT32 datalogging, a self-contained sub-project with its own
  Makefile. Third-party (CC Dharmani); see [`../NOTICE.md`](../NOTICE.md). One
  unattributed file was removed from it before publication.
- **`adc_ad7715.c` and `ad7715/`** — driver for an AD7715 16-bit sigma-delta ADC,
  the front end for a load-cell/bridge force-sensing path that was explored but
  not adopted. **The two copies have diverged** and are kept as-is rather than
  silently reconciled: `adc_ad7715.c` in this directory is the adapted AVR
  version; `ad7715/adc_ad7715.c` is a longer variant. Neither is compiled.
- **`samples.c`** — sampling experiments.
- **`lcd.c`** — 8051/Keil-style code (`P3 = 1; Call writecom(0x30);`) pasted from
  an LCD datasheet example. Not valid AVR C; would not compile. Dead.

`0-README.txt` is the original 2013 note, kept for provenance.

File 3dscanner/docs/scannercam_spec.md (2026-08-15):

# ScannerCam iPhone App — MVP Technical Specification

Version 0.2 (revised after technical review — see "Revision notes" at the end).

## 0. Deployment environment

Concrete parameters for this build, as opposed to the general design below.

```text
Bundle identifier:   com.ariemeir.ScannerCam
Signing team ID:     YOUR_TEAM_ID
Minimum iOS target:  iOS 17
Xcode:               26.2
Swift:               6.2.3
Third-party deps:    none

Paired device:       <paired iPhone>
Hardware:            iPhone 12 (iPhone13,2)
Device ID:           <DEVICE_UDID>
Device codename:     saru

Controller codename: shika (pulls images; owns capture/turntable orchestration)
API port:            8765
Networks:            Wi-Fi (LAN, primary) and Tailscale (remote/fallback)
Tailscale hostname:  saru
Tailscale IP:        100.x.y.z
```

Because the app must also be reachable over Tailscale, the server should bind
`0.0.0.0` (all interfaces) rather than only the Wi-Fi interface — Tailscale
presents as its own interface (`utun*`) with the `100.x.y.z` address.
Bonjour advertisement remains LAN-only by nature; when `shika` is off the home
network it should address the phone directly by Tailscale IP/hostname rather
than relying on discovery.

## 1. Purpose

ScannerCam turns an iPhone 12 into a remotely controlled still-image camera for a tabletop photogrammetry scanner.

The app must:

* Capture one high-quality JPEG on command.
* Store images locally, grouped by project.
* Use deterministic file names.
* Expose a local HTTP API over Wi-Fi (and Tailscale — see §0).
* Allow the controller (`shika`) to list and download images.
* Allow deletion of one project or all local scan data.
* Keep camera configuration stable throughout a project.
* Provide a minimal on-device preview and status interface.
* Require no cloud service, account, iCloud synchronization, or app-guided transfer process.

`shika` (the controller) is responsible for:

* Deciding when to capture.
* Deciding which project and frame number to use.
* Controlling or simulating turntable movement.
* Pulling images from the iPhone.
* Verifying downloads.
* Deleting iPhone-side files after successful transfer.

`saru` (the iPhone) is responsible for:

* Camera operation.
* Local image persistence.
* Serving its stored files.
* Reporting camera and storage state.

Apple's supported still-photo capture path is an `AVCaptureSession` with `AVCapturePhotoOutput`; each capture uses a fresh `AVCapturePhotoSettings` instance and receives the completed image through the capture delegate.

---

# 2. Scope

## 2.1 MVP scope

The MVP supports:

* One rear camera: iPhone 12 main wide camera, nominally 1×.
* JPEG output.
* Full available 4:3 still-photo resolution.
* Landscape or portrait orientation selected before capture.
* Local HTTP API.
* One active capture request at a time.
* Multiple named projects.
* Deterministic frame numbering.
* Listing projects.
* Listing project images.
* Downloading individual JPEGs.
* Downloading a project manifest.
* Deleting one project.
* Deleting all projects.
* Basic health and camera-status endpoints.
* Optional API-token authentication.
* Bonjour advertisement for discovery.
* Manual focus/exposure locking from the UI.
* Automatic creation of a project on first capture.

## 2.2 Explicitly out of scope for MVP

* Video recording.
* RAW or ProRAW.
* HEIC output.
* Burst capture.
* Multi-camera capture.
* Background capture while the app is suspended.
* Internet access.
* Remote access outside the local network / Tailscale.
* Automatic upload to the Mac.
* Bluetooth control.
* Arduino communication from the iPhone.
* Reconstruction.
* On-device image processing.
* Automated object masking.
* App Store distribution.

---

# 3. Intended Operating Model

The app must be open and active on the iPhone during a scan.

Typical sequence:

1. Launch ScannerCam.
2. Grant camera and local-network permissions.
3. Connect iPhone and controller to the same Wi-Fi network (or Tailscale).
4. Position and configure the camera.
5. Lock focus, exposure, and white balance.
6. Start the local API server.
7. `shika` checks `/api/v1/health`.
8. `shika` sends a capture request for project `red_mug`, frame `000000`.
9. ScannerCam captures and stores the JPEG.
10. `shika` requests frame `000000`.
11. `shika` performs the placeholder or Arduino turntable movement.
12. Repeat.
13. `shika` lists the project and verifies all expected frames.
14. `shika` downloads remaining images.
15. `shika` optionally deletes the project from ScannerCam.

The app must not depend on sequential conversational state. Every request includes enough information to stand alone.

For example, this must work directly:

```http
GET /api/v1/projects/red_mug/images/34
```

There is no requirement to first "open" project `red_mug` in the API.

---

# 4. Project and File Model

## 4.1 Project identifier

Each scan belongs to a `project_id`.

Allowed characters:

```text
a-z
A-Z
0-9
-
_
```

Length:

```text
1–64 characters
```

Examples:

```text
red_mug
red-mug-v2
gearbox_20260714
scan_001
```

Invalid examples:

```text
red mug
../../Documents
red/mug
赤いマグ
```

Unicode display names can come later. The MVP identifier remains ASCII-safe to avoid path and scripting headaches.

The server must reject invalid project IDs with HTTP `400`.

## 4.2 Frame number

Each image has an integer `frame`.

Range:

```text
0–999999
```

Frame numbers are formatted as six decimal digits:

```text
000000
000001
000034
000071
```

Using six digits avoids renaming if a future scan exceeds 9,999 captures.

## 4.3 Angle

Each capture request may include:

```json
"angle_degrees": 170.0
```

This value is metadata only. ScannerCam does not move the turntable and does not infer position.

Valid range:

```text
0.0 <= angle_degrees < 360.0
```

It may be omitted or set to `null`.

## 4.4 File naming format

**Revision note:** the original draft encoded angle into the filename
(`frame_<frame>_angle_<angle>.jpg`). Angle is informational and mutable
(overwrite can change it), while frame is the canonical, immutable identity —
encoding a mutable value into a supposedly-stable filename created an
overwrite bug (see §5.4). The filename is now frame-only; angle lives only in
the manifest and in the `Content-Disposition` header on download.

JPEG filename on disk:

```text
frame_<frame:06d>.jpg
```

Examples:

```text
frame_000000.jpg
frame_000001.jpg
frame_000034.jpg
```

This filename is an internal storage detail. Clients never need to construct
or parse it — they address images by `project_id` + `frame` through the API
(§8.8). For a human-friendly name on download, the server sets
`Content-Disposition` with a synthesized name that includes angle when known:

```text
frame_000034_angle_170.000.jpg
frame_000034_angle_unknown.jpg
```

## 4.5 Local directory structure

ScannerCam stores long-lived user-managed capture files beneath its app Documents directory. Apple documents the Documents directory as suitable for files managed by the user, within the app sandbox.

Logical structure:

```text
Documents/
└── ScannerCam/
    ├── app_state.json
    └── projects/
        └── red_mug/
            ├── project.json
            ├── manifest.json
            └── images/
                ├── frame_000000.jpg
                ├── frame_000001.jpg
                └── frame_000002.jpg
```

All file operations use Foundation `FileManager`, which supports creating, listing, moving, copying, and deleting files and directories.

## 4.6 Project metadata

`project.json`:

```json
{
  "schema_version": 1,
  "project_id": "red_mug",
  "created_at": "2026-07-14T12:30:00.000+09:00",
  "updated_at": "2026-07-14T12:42:12.000+09:00",
  "device": {
    "model": "iPhone 12",
    "system_version": "17.0"
  },
  "camera": {
    "position": "back",
    "lens": "wide",
    "requested_zoom_factor": 1.0,
    "output_format": "jpeg",
    "orientation": "landscapeRight"
  }
}
```

## 4.7 Manifest

`manifest.json` is rewritten atomically after every successful capture.

Example:

```json
{
  "schema_version": 1,
  "project_id": "red_mug",
  "image_count": 2,
  "images": [
    {
      "frame": 0,
      "angle_degrees": 0.0,
      "filename": "frame_000000.jpg",
      "captured_at": "2026-07-14T12:30:05.231+09:00",
      "size_bytes": 2840291,
      "width": 4032,
      "height": 3024,
      "sha256": "..."
    },
    {
      "frame": 1,
      "angle_degrees": 5.0,
      "filename": "frame_000001.jpg",
      "captured_at": "2026-07-14T12:30:11.918+09:00",
      "size_bytes": 2815577,
      "width": 4032,
      "height": 3024,
      "sha256": "..."
    }
  ]
}
```

The manifest order is ascending by frame number.

**Scaling note:** the manifest is fully rewritten on every capture. This is
fine at MVP scale (tens to low hundreds of frames per project) but becomes a
real per-capture cost for very large projects. The six-digit frame budget
(up to 999,999) is future headroom, not an MVP target — if projects routinely
grow past a few hundred frames, revisit this (e.g. an append-only log plus a
periodically-compacted manifest) rather than assuming the full-rewrite
approach scales indefinitely.

---

# 5. Capture Behavior

## 5.1 Camera selection

Default device:

```text
Back-facing wide-angle camera
```

Do not use:

* Front camera.
* Ultra-wide camera.
* Digital zoom.
* Portrait mode.
* Live Photos.
* Flash.
* Automatic lens switching.

The app should verify the selected physical device and expose its identity through the status API.

## 5.2 Output format

MVP output:

```text
JPEG
```

Requirements:

* Highest practical still-image dimensions supported by the active camera configuration.
* 4:3 aspect ratio.
* Quality-prioritized capture.
* No thumbnail-only output.
* No recompression after AVFoundation produces the JPEG.
* Preserve embedded EXIF metadata where available.

AVFoundation supports explicit capture quality prioritization on photo output.

## 5.3 Capture lifecycle

A capture request proceeds as follows:

1. Validate request.
2. Validate camera state.
3. Reject if another capture is active.
4. Resolve project directory.
5. Check whether target frame already exists (`frame_<frame:06d>.jpg` — a
   direct existence check, since filename no longer depends on angle).
6. Create a new `AVCapturePhotoSettings`.
7. Initiate capture.
8. Receive processed photo data.
9. Validate non-empty JPEG data.
10. Write to a temporary file.
11. Compute SHA-256.
12. Atomically rename the temporary file to its final filename.
13. Update manifest atomically.
14. Return success response.

Temporary filename:

```text
.pending_<UUID>.jpg
```

A final image must never appear through the API until the complete file has been written successfully.

## 5.4 Existing frame behavior

Default behavior:

```text
reject duplicate frame
```

If `frame_000034.jpg` already exists, return:

```http
409 Conflict
```

The request may explicitly allow replacement:

```json
{
  "project_id": "red_mug",
  "frame": 34,
  "angle_degrees": 170.0,
  "overwrite": true
}
```

With overwrite enabled:

1. Capture new image to a temporary file.
2. Verify new image.
3. Atomically rename the temporary file over `frame_000034.jpg`.
4. Update the manifest (including the new `angle_degrees`, which may differ
   from the previous value — since the filename is frame-only, this is a
   plain overwrite with no orphaned file from the old angle).
5. Return `"overwritten": true`.

## 5.5 Capture serialization

Only one capture may run at a time.

A second capture request received during capture returns:

```http
409 Conflict
```

Error code:

```json
{
  "error": {
    "code": "capture_in_progress",
    "message": "Another capture is currently in progress."
  }
}
```

No queue is required in the MVP. `shika` owns retry behavior.

## 5.6 Focus and exposure

The app UI supports:

* Tap-to-focus on preview.
* Tap-and-hold or button to lock focus.
* Lock exposure.
* Lock white balance.
* Unlock all.
* Exposure compensation slider.
* Optional manual focus slider where supported.

API capture must not silently refocus before every image when focus lock is enabled.

Status reports (this exact shape is returned both embedded in `GET /status`
and would be used by any future focus API — see revision note in §8.2):

```json
{
  "focus": {
    "mode": "locked",
    "lens_position": 0.43,
    "adjusting": false
  },
  "exposure": {
    "mode": "locked",
    "duration_seconds": 0.008333,
    "iso": 80,
    "target_offset": 0.0,
    "adjusting": false
  },
  "white_balance": {
    "mode": "locked",
    "adjusting": false
  }
}
```

A capture request may require locks:

```json
{
  "require_locks": true
}
```

When required and the camera is not locked, return `409`.

## 5.7 Orientation

The user selects one fixed output orientation in the app:

```text
portrait
portraitUpsideDown
landscapeLeft
landscapeRight
```

The app must not let incidental device motion rotate individual JPEGs differently during one project.

The active orientation is included in project metadata and capture responses.

---

# 6. Network Model

## 6.1 Transport

The app runs a local HTTP server while in the foreground.

Default port:

```text
8765
```

Base URL examples:

```text
http://192.168.1.42:8765           # LAN
http://100.x.y.z:8765         # Tailscale (saru)
```

The server binds `0.0.0.0` so both the Wi-Fi and Tailscale (`utun*`)
interfaces are reachable (see §0).

The app also advertises via Bonjour on the LAN:

```text
Service type: _scannercam._tcp
Instance name: ScannerCam-saru
```

Bonjour provides zero-configuration service discovery on a local network; it
does not cover the Tailscale path, where `shika` addresses the phone directly
by hostname (`saru`) or IP (`100.x.y.z`).

The app uses Apple's Network framework for TCP networking. Apple describes Network framework as the platform API for direct access to protocols such as TCP and UDP.

**HTTP implementation scope (revision note):** the MVP HTTP server is a
deliberately minimal HTTP/1.1 implementation with no third-party
dependencies. To keep that tractable, it explicitly does **not** implement
persistent connections or chunked transfer encoding. Every response:

* Sets `Content-Length` accurately (no chunked encoding).
* Sets `Connection: close`.
* Closes the TCP connection after the response is fully written.

This is a deliberate MVP cut, not an oversight — most HTTP/1.1 clients
(including `curl`) default to keep-alive and will otherwise sit waiting for
more bytes after a response that doesn't explicitly close. `shika`'s HTTP
client should not assume connection reuse.

## 6.2 Local-network permission

The app must include:

```text
NSLocalNetworkUsageDescription
```

Suggested text:

```text
ScannerCam uses your local network so your Mac can trigger captures and download scan images.
```

Apps accessing the local network must provide this usage description, and iOS prompts the user the first time local-network access is attempted.

The app must also declare its Bonjour service type in `NSBonjourServices`.

## 6.3 Authentication

MVP should use a shared bearer token even on the home LAN.

The app generates a random token on first launch:

```text
32 random bytes, base64url encoded
```

Example:

```text
Nz9rp1MaJjX_yD0qDt1qa3GpQdk5d_hvF14VcHqk18M
```

The token is displayed in the Settings screen and stored in the Keychain.

Every API request except `/api/v1/health` requires:

```http
Authorization: Bearer <token>
```

Token comparison must be constant-time (do not use `==` on the raw strings)
to avoid a timing side-channel, even though the practical exposure on a
private LAN/Tailscale tailnet is low.

Unauthorized response:

```http
401 Unauthorized
```

The health endpoint may return only minimal, non-sensitive information without authentication.

## 6.4 HTTP versus HTTPS

For a private MVP reachable over LAN and Tailscale, plain HTTP is acceptable provided:

* The bearer token is treated as local-network/tailnet-only.
* The Wi-Fi network is trusted.
* The server binds only to local/tailnet interfaces (never a public one).
* The user understands this is not safe over public/untrusted Wi-Fi outside the tailnet.

Tailscale's own WireGuard-based encryption covers the tailnet path; plain
HTTP inside that tunnel is materially different from plain HTTP on an open
network. Plain LAN HTTP is still acceptable for MVP under the constraints
above.

Later versions may add TLS or direct device pairing.

App Transport Security primarily governs outbound URL-loading connections made by apps; ScannerCam is acting as the local server, so ATS does not apply here.

---
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

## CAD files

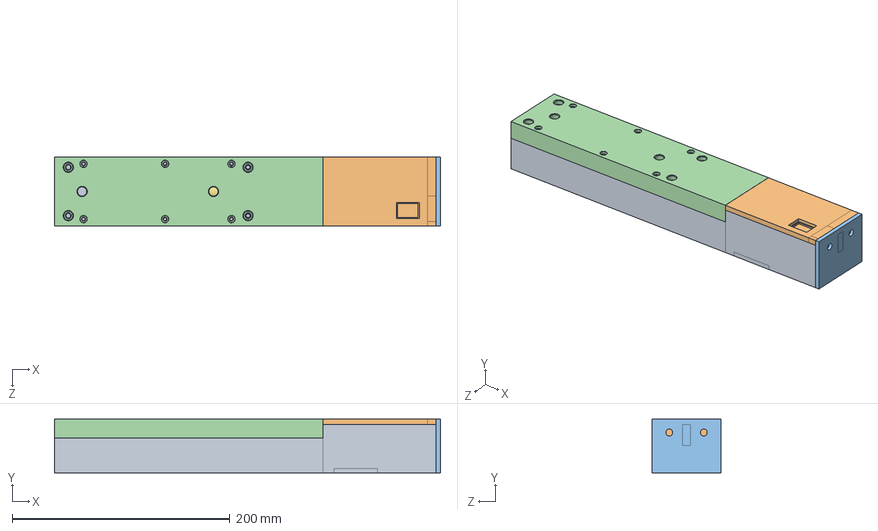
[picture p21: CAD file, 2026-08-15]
roboimplant/hardware/enclosure/new_controller_enclosure_assembly.SLDASM
354.6 x 49.5 x 63.6 mm
enclosure_bottom
enclosure_circuit_cover
enclosure_battery_cover
motor_top_cover.SLDDRW
Mounting Plate
Spyraflo-PB1-250-N_PillowBlock
RE-25-118740

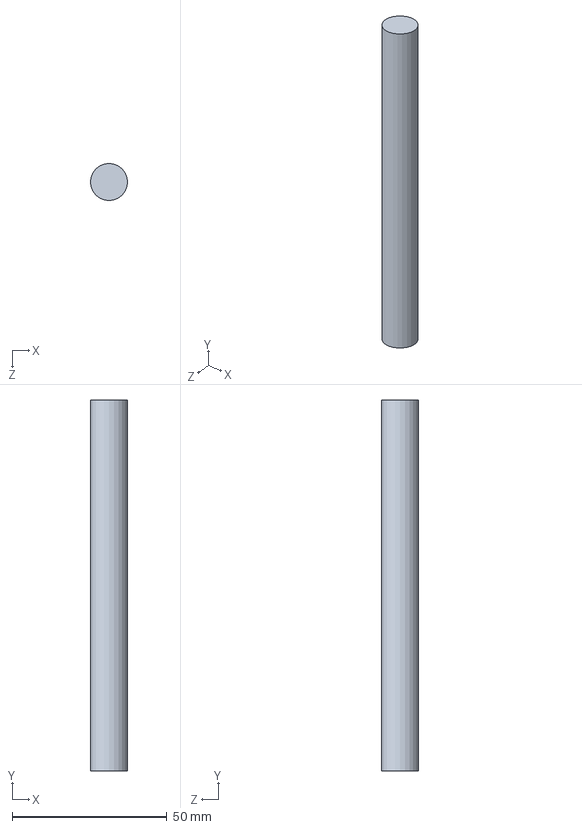
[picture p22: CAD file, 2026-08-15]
roboimplant/hardware/enclosure/6mm_rod.SLDPRT
12.0 x 120.0 x 12.0 mm

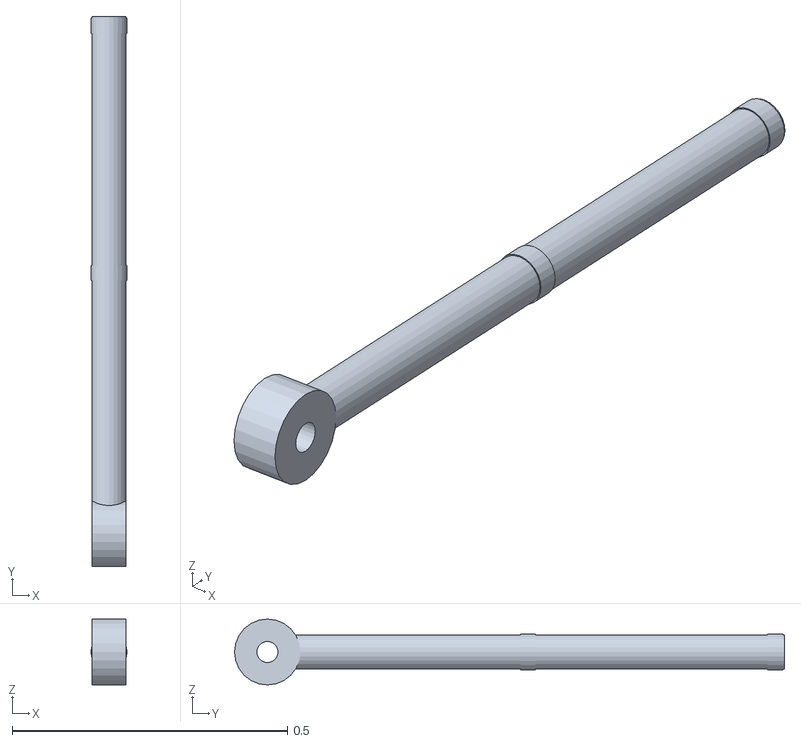
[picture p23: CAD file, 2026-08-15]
roboimplant/models/spine/models/rod.obj
0.0657 x 1.00 x 0.12

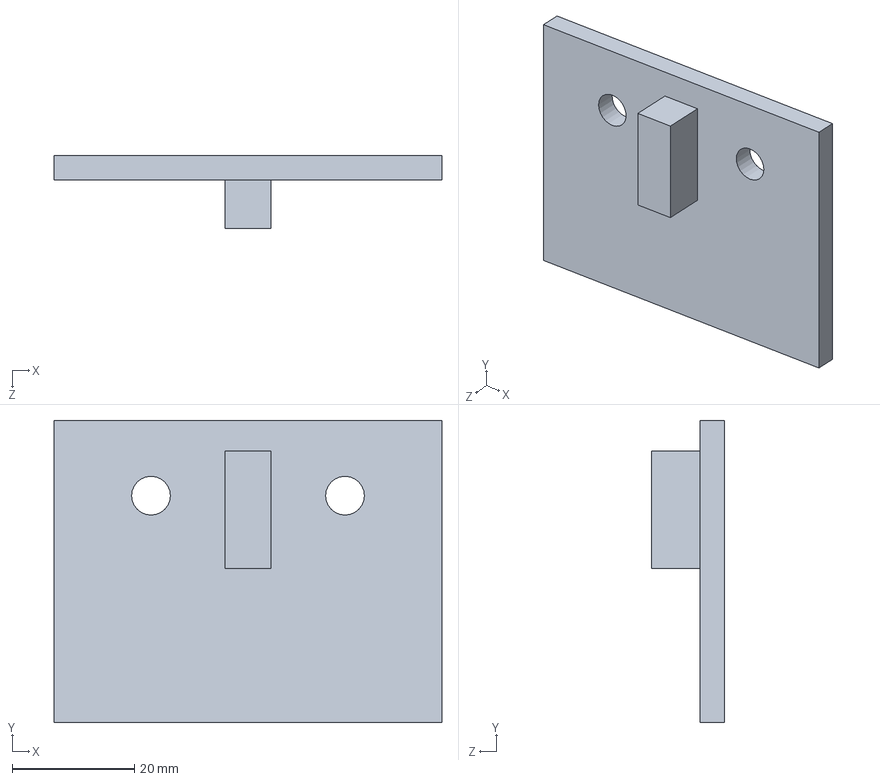
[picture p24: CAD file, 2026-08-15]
roboimplant/hardware/enclosure/enclosure_battery_cover.SLDPRT
63.5 x 49.5 x 12.0 mm

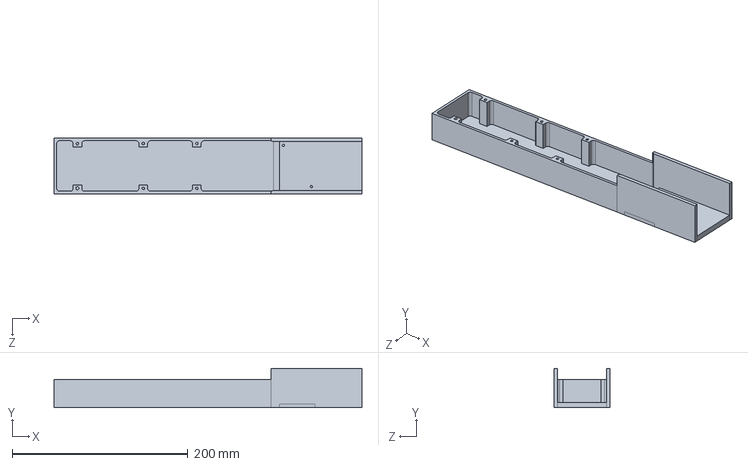
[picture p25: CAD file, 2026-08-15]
roboimplant/hardware/enclosure/enclosure_bottom.SLDPRT
350.6 x 44.5 x 63.6 mm

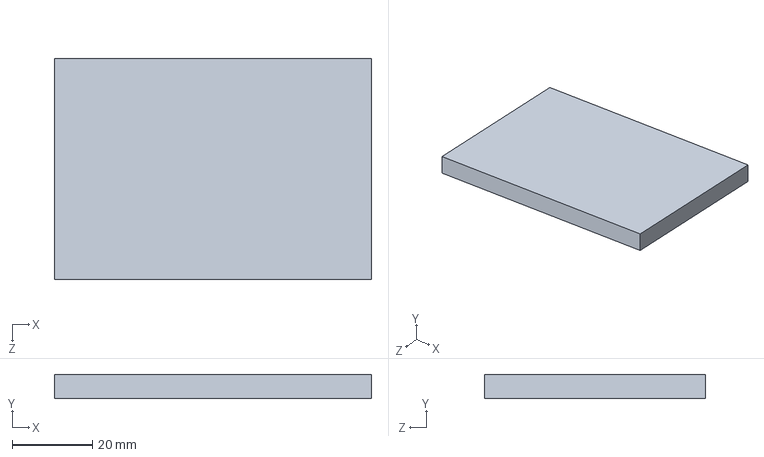
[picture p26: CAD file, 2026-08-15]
roboimplant/hardware/enclosure/pcb.SLDPRT
78.9 x 6.00 x 55.0 mm

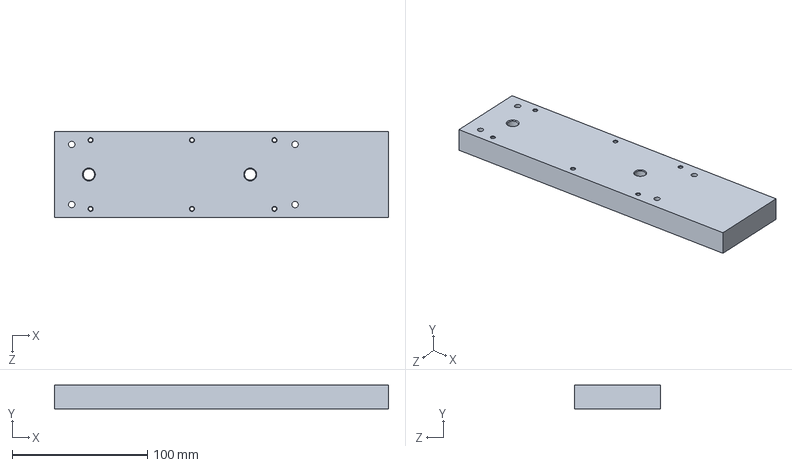
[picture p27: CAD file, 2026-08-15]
roboimplant/hardware/enclosure/motor_top_cover.SLDDRW.SLDPRT
246.8 x 17.5 x 63.5 mm

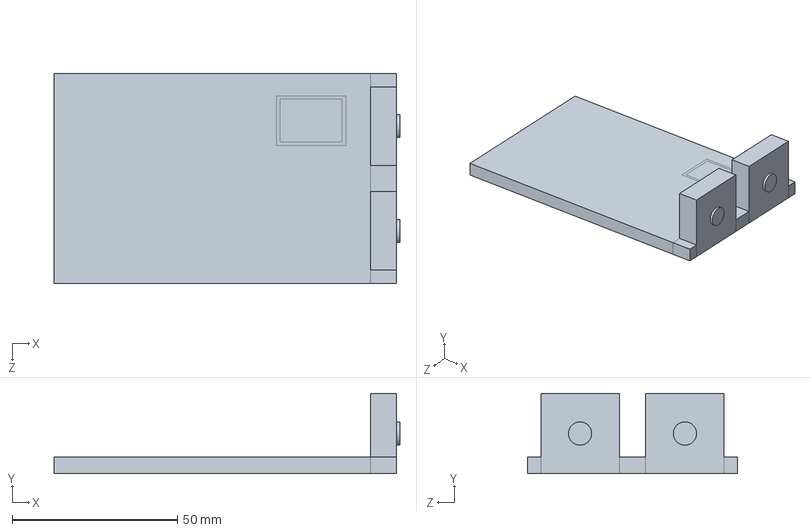
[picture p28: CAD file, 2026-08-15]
roboimplant/hardware/enclosure/enclosure_circuit_cover.SLDPRT
104.8 x 24.3 x 63.5 mm

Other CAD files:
roboimplant/models/spine/Metal Rod.skp

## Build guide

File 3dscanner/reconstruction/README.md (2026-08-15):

# Reconstruction — photos → 3D model → STL

Turns a captured turntable session (`scans/completed/<id>/images/frame_*.jpg`)
into a textured mesh and a printable STL, **entirely on the local Mac** — no cloud
photogrammetry service.

**→ [Browse this directory on GitHub](https://github.com/ariemeir/technical-portfolio/tree/main/3dscanner/reconstruction)**
· [`objcap/main.swift`](https://github.com/ariemeir/technical-portfolio/blob/main/3dscanner/reconstruction/objcap/Sources/objcap/main.swift)
· [`scripts/repair.py`](https://github.com/ariemeir/technical-portfolio/blob/main/3dscanner/reconstruction/scripts/repair.py)

## Why Apple Object Capture (not COLMAP) on Apple Silicon

COLMAP's dense stereo (`patch_match_stereo`) is **CUDA-only** — it hard-errors
on Apple Silicon ("Dense stereo reconstruction requires CUDA"). COLMAP would
give us only a sparse point cloud here. Apple's **Object Capture**
(`RealityKit.PhotogrammetrySession`) is GPU-accelerated on M-series, purpose-
built for object/turntable capture, and produces a near-watertight *textured
mesh* directly. So the mesh stage uses Object Capture. (If you later move to an
NVIDIA/Linux box, COLMAP + OpenMVS becomes viable for dense work.)

## Pipeline

```
scans/completed/<id>/images/frame_*.jpg
        │  reconstruction/scripts/reconstruct.sh <session_dir> [detail]
        ▼
output/meshes/<id>.usdz   textured mesh — Quick Look it (spacebar in Finder)
output/meshes/<id>/       textured OBJ *bundle* — baked_mesh_*.obj + .mtl + textures
output/meshes/<id>.stl    geometry only — for 3D printing (needs repair, below)
```

- **Detail levels:** `preview` (fast, rough) · `reduced` · `medium` (default) ·
  `full` · `raw` (slowest, densest). Start with `reduced` to sanity-check, then
  `full` for the keeper.
- **Output formats:** Object Capture writes **USDZ** (single file) and **OBJ**
  (a *bundle*: `baked_mesh_*.obj` + `.mtl` + texture PNGs). OBJ output **must be a
  directory** — RealityKit rejects a plain `foo.obj` file path with
  `invalidOutput`, so `objcap` writes the bundle into `<id>/`. Object Capture
  does **not** write STL — `reconstruct.sh` converts the bundle's OBJ→STL via
  `assimp` (STL is geometry only; textures are dropped).
- **Watertight?** The Poisson-style surface is topologically closed, but a
  single-ring turntable scan never photographs the object's **underside**, so
  the base is fabricated — closed, but geometrically crude. For printing, run
  `scripts/repair.py` (below), which automates the repair pass.

## Print preparation — `scripts/repair.py`

A PyMeshLab tool that turns a reconstruction into a solid a slicer will accept:

```bash
./reconstruction/scripts/repair.py in.stl out.stl \
    --normal-to-z --diameter-mm 100 --smooth-base 3.5
```

| Stage | What it does |
|---|---|
| weld + drop strays | Merge duplicate vertices, remove small disconnected components |
| repair + close holes | Fix non-manifold edges/vertices, fill every open boundary → **watertight** |
| `--normal-to-z` | PCA-orient the flat face's normal to +Z, with a determinant check so the mesh is never mirrored |
| `--diameter-mm N` | STL is unitless and slicers read millimetres — scale the widest in-plane extent to *N* mm |
| `--smooth-base MM` | Taubin-smooth **only** the bottom band, softening the fabricated base while leaving detailed geometry untouched |
| seat | Centre in XY, sit flat on Z=0 |

### ⚠️ Repair before drilling, never after

Close-holes fills **every** open boundary — including see-through holes you have
just drilled. Run the repair pass first to get a clean watertight solid, *then*
drill it (Blender boolean difference, `Manifold` solver on 5.x). A boolean through
a closed solid yields clean tunnels that preserve watertightness; drilling a messy
mesh leaves open boundaries, and an exact boolean against self-intersecting
geometry can collapse the mesh entirely.

## Build the tool (once)

```bash
cd reconstruction/objcap && swift build -c release
brew install assimp          # for the OBJ→STL step
```

`objcap` is a ~90-line Swift CLI (`reconstruction/objcap/`) wrapping
`PhotogrammetrySession`. Requires macOS 14+ and an Apple Silicon (or AMD) GPU.

## Run

```bash
./reconstruction/scripts/reconstruct.sh scans/completed/<id> full
# or drive the CLI directly:
./reconstruction/objcap/.build/release/objcap <imagesDir> medium out.usdz out.obj
```

## Capturing a *good* scan (matters more than any setting)

Object Capture needs **viewpoint diversity + overlap** — the dry-run frames
(same pose, no rotation) correctly fail with `processError`. For a real scan:

- **Object:** matte, opaque, textured, rigid, asymmetric. Avoid shiny, clear,
  or featureless surfaces.
- **Coverage:** 36–72 frames around a full turn (10° or 5° steps), each frame
  overlapping its neighbours by a lot.
- **Camera:** locked focus/exposure/white-balance (tap **Lock All** in
  ScannerCam), object filling most of the frame, stationary phone.
- **Lighting:** bright, even, diffuse; no hard moving shadows.
- Capture with `capture/controller/scan.py run --name <obj> --degrees 10`.

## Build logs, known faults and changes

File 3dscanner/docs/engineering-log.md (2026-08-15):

# Engineering Log

Decisions, bugs, and measurements recorded while building the scanner, adapted from
the project's working handoff document. Kept because the reasoning is often more
useful than the result — particularly the failures, which are the parts that
generalize.

Ordered roughly by subsystem rather than chronologically.

---

## Design decisions and why

### Filenames do not encode angle

The original design named files `frame_000034_angle_170.000.jpg`. This broke on
overwrite: re-capturing a frame at a corrected angle produced a *different*
filename than the one it was meant to replace, so "atomically replace the old file"
had no well-defined target and each changed-angle overwrite orphaned a JPEG.

Names are now `frame_%06d.jpg` — frame number only, the one value that never
changes. Angle lives in the manifest, and reaches clients through the
`Content-Disposition` header on download.

The general lesson: never encode a mutable attribute into an identifier that
something else relies on being stable.

### The HTTP server has no persistent connections

Every response carries `Connection: close`. There is no keep-alive and no chunked
transfer encoding, and `Content-Length` is always accurate.

This was a deliberate scope cut, taken to keep a from-scratch HTTP/1.1
implementation tractable, and it is documented in the spec rather than left for a
client author to discover. Clients — including the Python controller and any manual
`curl` — must not assume connection reuse.

### A capture blocks the request thread, on purpose

`POST /captures` holds the connection's handler for the duration of the exposure,
using a `DispatchSemaphore` to bridge AVFoundation's async completion callback into
the synchronous route handler.

This is intentional. Only one capture can physically run at a time regardless, and
the server has no concurrent connection model to surrender. It does mean a request
arriving mid-capture waits ~0.5–1 s. The semaphore wait is bounded at 25 s so a
wedged camera cannot block forever.

### Swift language mode 5, not 6

Pinned in `project.yml`, deliberately. The `NWListener`-based server and the
AVFoundation delegate patterns predate proper actor-isolation and `Sendable`
annotations, and doing that migration correctly was out of scope. The toolchain is
current; only strict-concurrency checking is relaxed.

### The controller never duplicates IR codes

`capture/controller/turntable/arduino_ir.py` loads
`firmware/turntable_ir/turntable.py` by path at runtime and reuses its gateway and
code table, rather than copying command values into the controller. It fails fast if
`START_PAUSE` is missing from the table. The firmware directory stays the single
source of truth for anything infrared.

### The idle timer is disabled while the server runs

A real bug, found in testing. The app is foreground-only by design, but nothing
stopped iOS from auto-locking the screen after a minute or two of inactivity, which
silently killed the server mid-session. Setting `isIdleTimerDisabled` while the
server is running fixed it.

A manual power-button lock still suspends the app. That is expected and documented
behaviour, not a bug.

---

## Bugs worth recording

### The server wedged completely, including `/health`

**Symptom.** During the first real controller run the entire server hung. Every
endpoint accepted the TCP connection and then never responded. Force-quit required.

**Wrong hypothesis.** The obvious suspect was the project routes, since those were
what the controller had just started exercising.

**Actual cause.** `HTTPServer` ran the `NWListener`, every connection's I/O, *and*
`router.handle` on **one shared serial `DispatchQueue`**. Several handlers block
that queue synchronously — the capture route's `semaphore.wait()`, the status
route's `sessionQueue.sync`. One blocked handler therefore starved the listener
itself, so nothing could be served, including endpoints that touch no shared state.

**Fix.** Each accepted connection now gets its own serial queue, so a blocked
request affects only itself. The capture semaphore also became bounded.

**Verification.** A 3-frame scan while hammering the previously-hung endpoints and
pinging `/health` five times a second: all endpoints 30–50 ms, zero failures.

### The image-list client looped forever

Surfaced while chasing the wedge, and unrelated to it. The Python client's
`list_images` assumed `offset`/`total` pagination; the API actually uses
`after_frame`/`has_more`. The cursor never advanced, so it re-fetched page one
indefinitely.

Fixed, and pinned with a regression test that walks a real two-page response. The
client also gained a defensive no-progress break.

### Infrared transmitted but nothing decoded it

The IR LED visibly flashed — confirmed on a phone camera — yet the turntable
ignored every command.

IRremote drives the sender's 38 kHz carrier PWM *and* the receiver's 50 µs sampling
interrupt from **the same hardware timer (Timer2)** on an Uno. With the receiver
active, its ISR steals cycles from the transmit path and the mark/space timing comes
out malformed: a signal is emitted, but not a valid NEC frame.

Every transmit is now wrapped in receiver-disable / receiver-enable. The minimal
production gateway sketch has no receiver at all and so avoids the problem entirely.

### Object Capture rejected the OBJ output path

`PhotogrammetrySession` returned `invalidOutput` at submit time for OBJ export.

RealityKit writes OBJ as a *bundle* — a directory containing `baked_mesh_<hash>.obj`,
its `.mtl`, and textures — so it requires a directory URL. Subtly, the URL must also
carry `isDirectory: true`. Building `URL(fileURLWithPath: "foo.obj")` and calling
`.deletingPathExtension()` yields a URL flagged as a *file*, which is rejected.

Two consequences, both fixed: the directory URL is now constructed explicitly, and
the shell pipeline globs for `baked_mesh_*.obj` inside the bundle instead of
expecting `<id>.obj`.

### Re-running a reconstruction failed

RealityKit's `modelFile` request refuses to overwrite an existing output and aborts
at submit. Re-running a session at a different detail level — `reduced` first for a
sanity check, then `full` — therefore always failed the second time. The pipeline
now removes prior outputs for that session ID before running.

### Two failed authentications caused by the UI, not the auth code

The Settings screen originally displayed the 43-character random API token as plain,
unselectable text. Hand-transcribing it failed twice — once with an extra character,
once missing a hyphen — and both times presented as a `401` that looked like an auth
bug.

Fixed with selectable text plus a copy button, and later a custom-token field so a
memorable value can be set instead. Worth remembering as a debugging heuristic:
suspect a mis-copied credential before suspecting the credential-checking code.

---

## Platform evaluation: COLMAP

COLMAP was the initial choice for reconstruction and was **removed after testing**.

Its dense stereo stage (`patch_match_stereo`) is CUDA-only and hard-errors on Apple
Silicon with an explicit "Dense stereo reconstruction requires CUDA". On this
hardware it could therefore only ever produce a sparse point cloud — never a mesh —
which is not a partial result but a dead end for this use case.

Replaced with Apple Object Capture, which is GPU-accelerated on M-series, purpose
built for object and turntable capture, and outputs a near-watertight *textured*
mesh directly.

**The decision reverses** only if dense reconstruction moves to an NVIDIA/Linux
machine, at which point COLMAP plus OpenMVS becomes worth revisiting.

---

## Operating the rig

### The turntable must be armed before a run

The controller only ever sends `START_PAUSE`. Everything else — direction, speed,
continuous mode — is set once by the operator over IR beforehand:

```
irctl.py send SPEED_DOWN SPEED_DOWN SPEED_DOWN CW ROTATE_CONTINUOUS --gap 1.0
```

**The trap:** `ROTATE_CONTINUOUS` is not a passive mode selection — it starts the
table spinning immediately. The arming sequence therefore leaves the table *running*,
and one `START_PAUSE` must be sent to stop it before starting a scan:

```
irctl.py send START_PAUSE
```

Skip that and the controller, which assumes the table starts stopped, inverts every
toggle for the whole run. Because `START_PAUSE` is an unreadable toggle, the only
confirmation available is visual. A completed run leaves the table armed and
stopped, so back-to-back scans need no re-arming.

### Step size

`--degrees` must divide evenly into 360. At the slowest speed a 5° step is roughly a
0.26 s pulse and still lands reliably; finer than that, motor spin-up and coast
begin to dominate the commanded interval and rotation becomes inconsistent.

---

## Results

### What makes a scan succeed

The rig and pipeline worked from the first run. Subject and scene choice turned out
to dominate outcomes.

| Round | Subject / scene | Frames used | Result |
|---|---|---|---|
| 1 | Glossy mug, cluttered desk with a **monitor** behind | — | hard failure |
| 2 | Glossy mug, light tent, matte backdrop | 10 / 36 | partial ~90° shell |
| 3 | **Matte textured ceramic flower**, light tent | 36 / 36 | clean full mesh |
| 4 | Same flower, 5° steps | 72 / 72 | clean; 87,394 triangles at `full` |

**A feature-rich static background breaks the solve.** A monitor displaying text is
the worst case. The object rotates and the background does not, and the
reconstruction cannot reconcile two rigid scenes moving relative to each other.
Anything sitting *on* the turntable disc — an alignment arrow, a ruler — is
harmless, because it rotates with the object and stays consistent.

**Surface matters more than resolution.** Matte, textured, asymmetric subjects
register reliably. Glossy, rotationally symmetric ones — a ribbed mug — drop frames
past roughly 90°, because every angle looks alike to the feature matcher and
specular highlights slide across the surface rather than staying fixed to it.

### Detail levels — 144 images at 48 MP, on an M4

| Level | Time | Triangles |
|---|---|---|
| `reduced` | 6 m 20 s | 25 k |
| `full` | 6 m 52 s | 100 k |
| `raw` | 10 m 56 s | 212 k |

**`reduced` is only 32 seconds faster than `full`.** Roughly 90% of runtime is
ingesting and solving the images, which is identical at every level; only the final
mesh and texture generation differs. `reduced` therefore buys a lighter file, not a
faster run — and `raw` is the only level that adds genuinely new geometry, at about
2.1× `full`. USDZ file size tracks texture resolution, not triangle count.

### Multiple camera elevations

One turntable ring is one camera elevation, and it never sees the top or underside
well. Additional rings are shot by tilting the *camera* between full 360° runs — the
object must not move. All rings then reconstruct together in a single session, and
Object Capture fuses the poses.

A mid ring (72 frames) plus a low "under" ring (72 frames) fused **128 of 144**
frames. The under ring alone was poor — 16 near-edge-on frames dropped, since a flat
disc is ambiguous viewed edge-on — but combined, it **corrected the object's
thickness**: the mid ring had over-rounded an edge it could never observe, and the
under ring's edge-on views pinned the true thin profile.

A top-down ring added little for a flat object, being largely redundant with the mid
ring. More rings help genuinely three-dimensional subjects. Fine surface detail comes
from `raw` detail and filling the frame, not from additional rings.

---

## Print preparation

`repair.py` (PyMeshLab) turns a reconstruction into a printable solid: weld → drop
stray components → repair non-manifold geometry → close holes → orient the flat
face's normal to +Z by PCA → scale the widest in-plane extent to a given millimetre
figure → Taubin-smooth only the bottom band → seat on Z=0.

```
repair.py in.stl out.stl --normal-to-z --diameter-mm 100 --smooth-base 3.5
```

produced a watertight 100 mm medallion, 17.4 mm thick, with its flat face
perpendicular to Z.

Object Capture's output is already *nearly* watertight — the `full`/`raw` flower had
a single 20-edge hole. The fabricated base is closed topologically but geometrically
crude, having never been photographed, which is what `--smooth-base` addresses.

### The drilling order trap

Punching see-through holes is done interactively in Blender, using a boolean
difference. The ordering matters and is easy to get backwards:

**Close-holes fills every open boundary — including the holes you just drilled.**
Running the repair pass after drilling silently undoes the drilling.

So: repair first, to a clean watertight solid; drill second. A boolean difference
through a closed solid yields clean tunnels that preserve watertightness. Drilling a
messy mesh leaves open boundaries, and an exact boolean against self-intersecting
geometry can collapse the mesh entirely.

Blender 5.x renamed the boolean solvers: `Float` (formerly "Fast"), `Exact`, and the
new **`Manifold`**, which is the right choice for watertight input. If the whole mesh
vanishes on a difference operation, the usual causes are flipped normals on the
cutter or target, an unapplied cutter scale, or a self-intersecting joined cutter.

---

## Downstream

The printed part is a master for a one-part open-pour silicone block mould — a
flat-backed medallion being the simplest case — cast in gypsum. Casting plaster
(Hydrocal or dental stone) holds detail considerably better than craft plaster of
Paris. Through-holes make thin, fragile mould posts and are best plugged for a first
mould.

---

## Corrections to the original working notes

Recorded because the original document asserted them confidently and they turned out
to be wrong.

- **Repository location.** An earlier note stated this tree had been folded into
  another repository as an ordinary subdirectory, and that tooling assuming it was
  its own git root was therefore incorrect. That is not what happened: the project
  is its own repository, with its own remote, and the repository named in that note
  does not exist. The note was stale and is superseded by this one.
- **Bonjour advertisement.** An earlier note stated that Bonjour advertisement code
  existed and that the unresolved `saru.local` hostname was therefore likely a
  Mac-side resolver quirk. Reading the code shows no `NWListener.service` is ever
  set — the service type is declared in `Info.plist` and the status endpoint reports
  a Bonjour name, but nothing advertises. The mDNS failure has a much simpler
  explanation than the one recorded.

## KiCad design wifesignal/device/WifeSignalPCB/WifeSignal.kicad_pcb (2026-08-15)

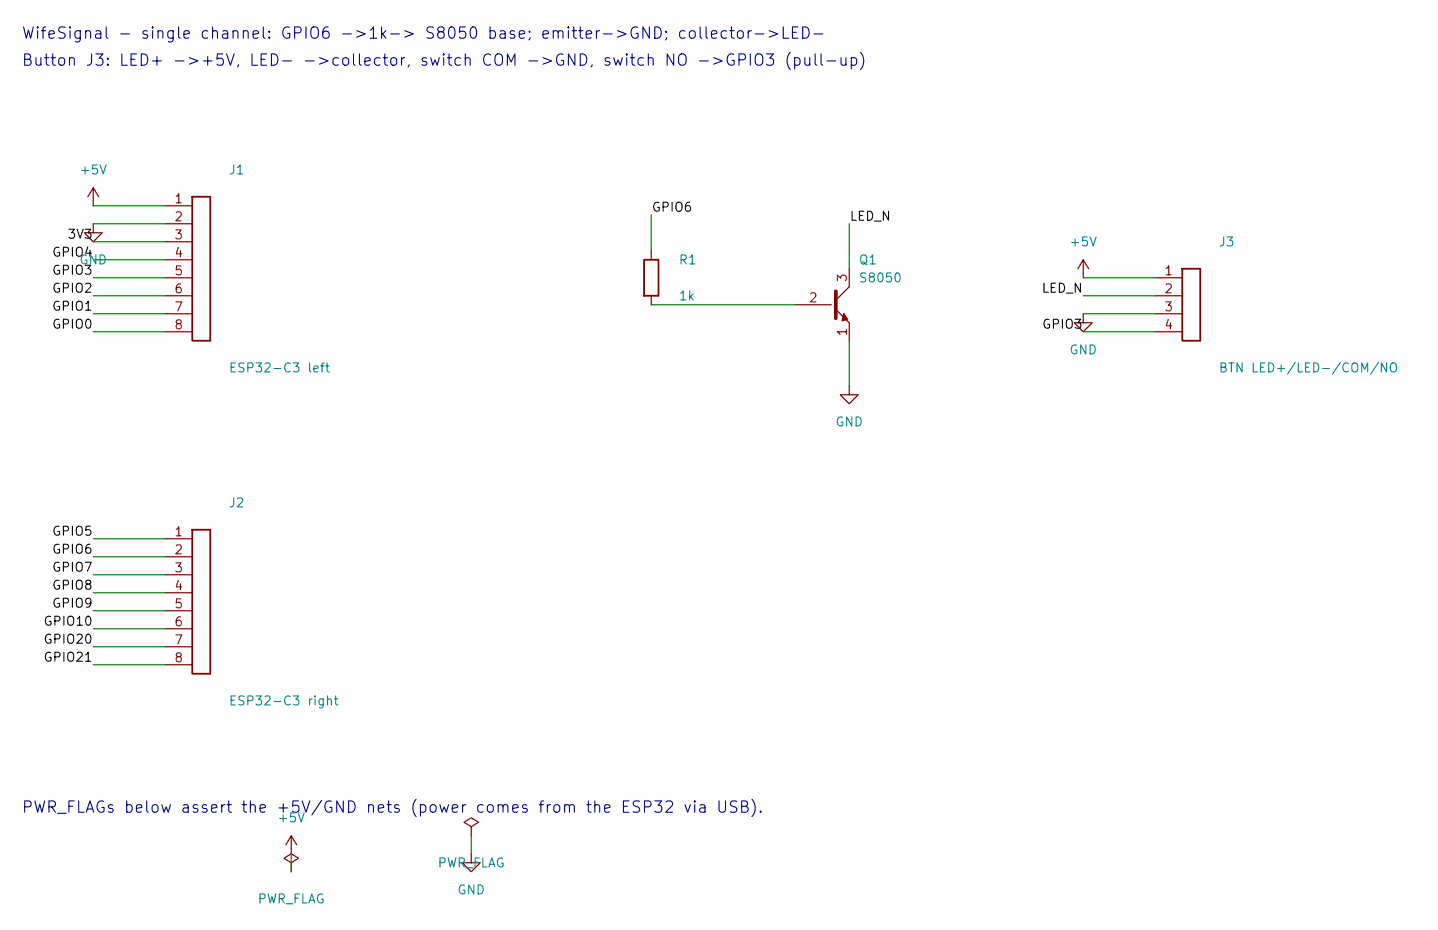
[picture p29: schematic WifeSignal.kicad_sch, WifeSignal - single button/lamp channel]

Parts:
J1: ESP32-C3 left; PinHeader_1x08_P2.54mm_Vertical
J2: ESP32-C3 right; PinHeader_1x08_P2.54mm_Vertical
J3: BTN LED+/LED-/COM/NO; PinHeader_1x04_P2.54mm_Vertical
Q1: S8050; TO-92_Inline
R1: 1k; R_Axial_DIN0207_L6.3mm_D2.5mm_P7.62mm_Horizontal

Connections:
+5V: J1.1, J3.1
/3V3: J1.3
/GPIO0: J1.8
/GPIO1: J1.7
/GPIO2: J1.6
/GPIO3: J1.5, J3.4
/GPIO4: J1.4
/GPIO5: J2.1
/GPIO6: J2.2, R1.1
/GPIO7: J2.3
/GPIO8: J2.4
/GPIO9: J2.5
/GPIO10: J2.6
/GPIO20: J2.7
/GPIO21: J2.8
/LED_N: J3.2, Q1.3 (C)
GND: J1.2, J3.3, Q1.1 (E)
unnamed: Q1.2 (B), R1.2

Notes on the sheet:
WifeSignal - single channel: GPIO6 ->1k-> S8050 base; emitter->GND; collector->LED-
PWR_FLAGs below assert the +5V/GND nets (power comes from the ESP32 via USB).
Button J3: LED+ ->+5V, LED- ->collector, switch COM ->GND, switch NO ->GPIO3 (pull-up)

Board: 2 copper layers, 5 parts (0 on the bottom side), 6 nets, no tracks yet.

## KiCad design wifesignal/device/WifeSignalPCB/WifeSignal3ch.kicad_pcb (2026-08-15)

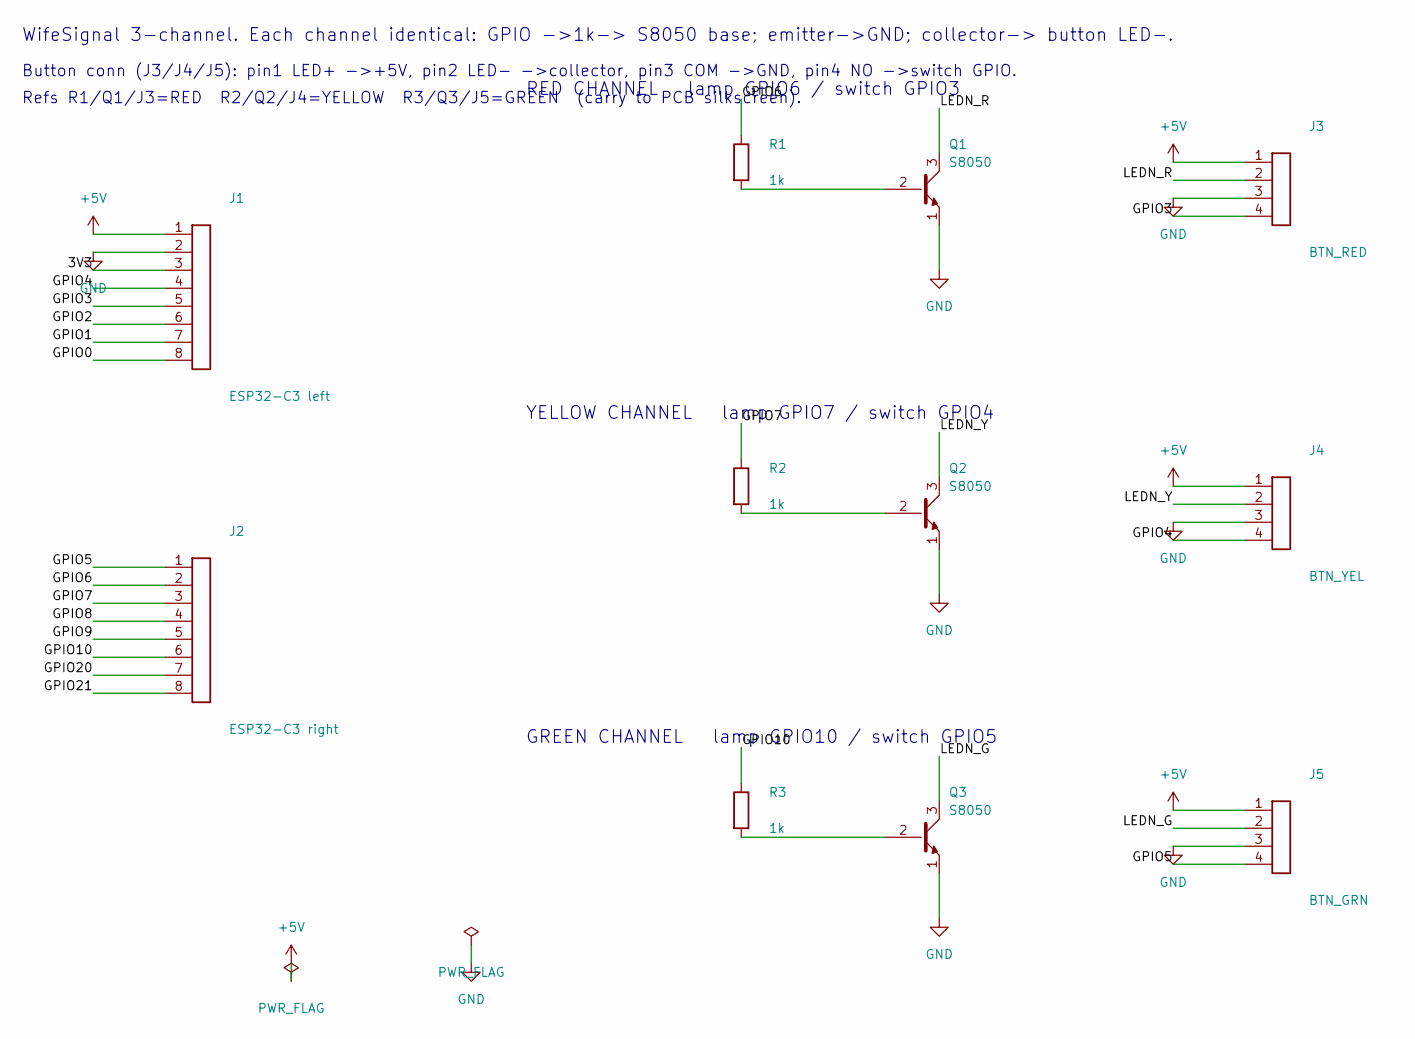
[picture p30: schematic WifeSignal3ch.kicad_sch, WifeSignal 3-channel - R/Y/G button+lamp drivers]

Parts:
J1: ESP32-C3 left; PinHeader_1x08_P2.54mm_Vertical
J2: ESP32-C3 right; PinHeader_1x08_P2.54mm_Vertical
J3: BTN_RED; PinHeader_1x04_P2.54mm_Vertical
J4: BTN_YEL; PinHeader_1x04_P2.54mm_Vertical
J5: BTN_GRN; PinHeader_1x04_P2.54mm_Vertical
Q1, Q2, Q3: S8050; TO-92_Inline
R1, R2, R3: 1k; R_Axial_DIN0207_L6.3mm_D2.5mm_P7.62mm_Horizontal

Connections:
+5V: J1.1, J3.1, J4.1, J5.1
/3V3: J1.3
/GPIO0: J1.8
/GPIO1: J1.7
/GPIO2: J1.6
/GPIO3: J1.5, J3.4
/GPIO4: J1.4, J4.4
/GPIO5: J2.1, J5.4
/GPIO6: J2.2, R1.1
/GPIO7: J2.3, R2.1
/GPIO8: J2.4
/GPIO9: J2.5
/GPIO10: J2.6, R3.1
/GPIO20: J2.7
/GPIO21: J2.8
/LEDN_G: J5.2, Q3.3 (C)
/LEDN_R: J3.2, Q1.3 (C)
/LEDN_Y: J4.2, Q2.3 (C)
GND: J1.2, J3.3, J4.3, J5.3, Q1.1 (E), Q2.1 (E), Q3.1 (E)
unnamed: Q1.2 (B), R1.2
unnamed: Q2.2 (B), R2.2
unnamed: Q3.2 (B), R3.2

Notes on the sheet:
GREEN CHANNEL lamp GPIO10 / switch GPIO5
RED CHANNEL lamp GPIO6 / switch GPIO3
Button conn (J3/J4/J5): pin1 LED+ ->+5V, pin2 LED- ->collector, pin3 COM ->GND, pin4 NO ->switch GPIO.
YELLOW CHANNEL lamp GPIO7 / switch GPIO4
Refs R1/Q1/J3=RED R2/Q2/J4=YELLOW R3/Q3/J5=GREEN (carry to PCB silkscreen).
WifeSignal 3-channel. Each channel identical: GPIO ->1k-> S8050 base; emitter->GND; collector-> button LED-.

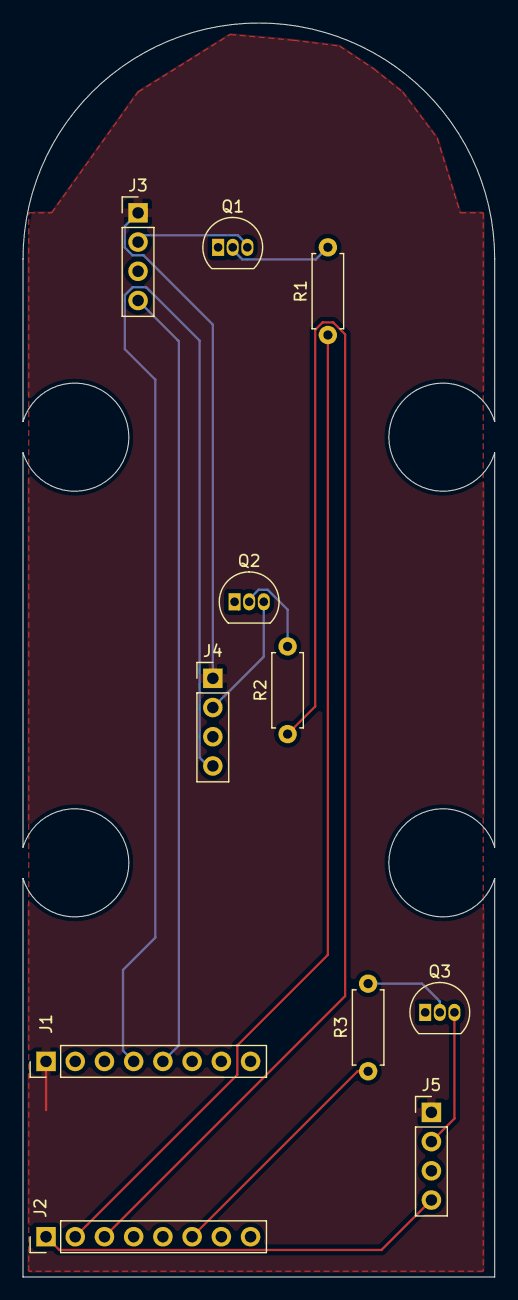
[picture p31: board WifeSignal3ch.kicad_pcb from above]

Board: 2 copper layers, 41.0 x 109.0 mm, 11 parts (0 on the bottom side), 14 nets.

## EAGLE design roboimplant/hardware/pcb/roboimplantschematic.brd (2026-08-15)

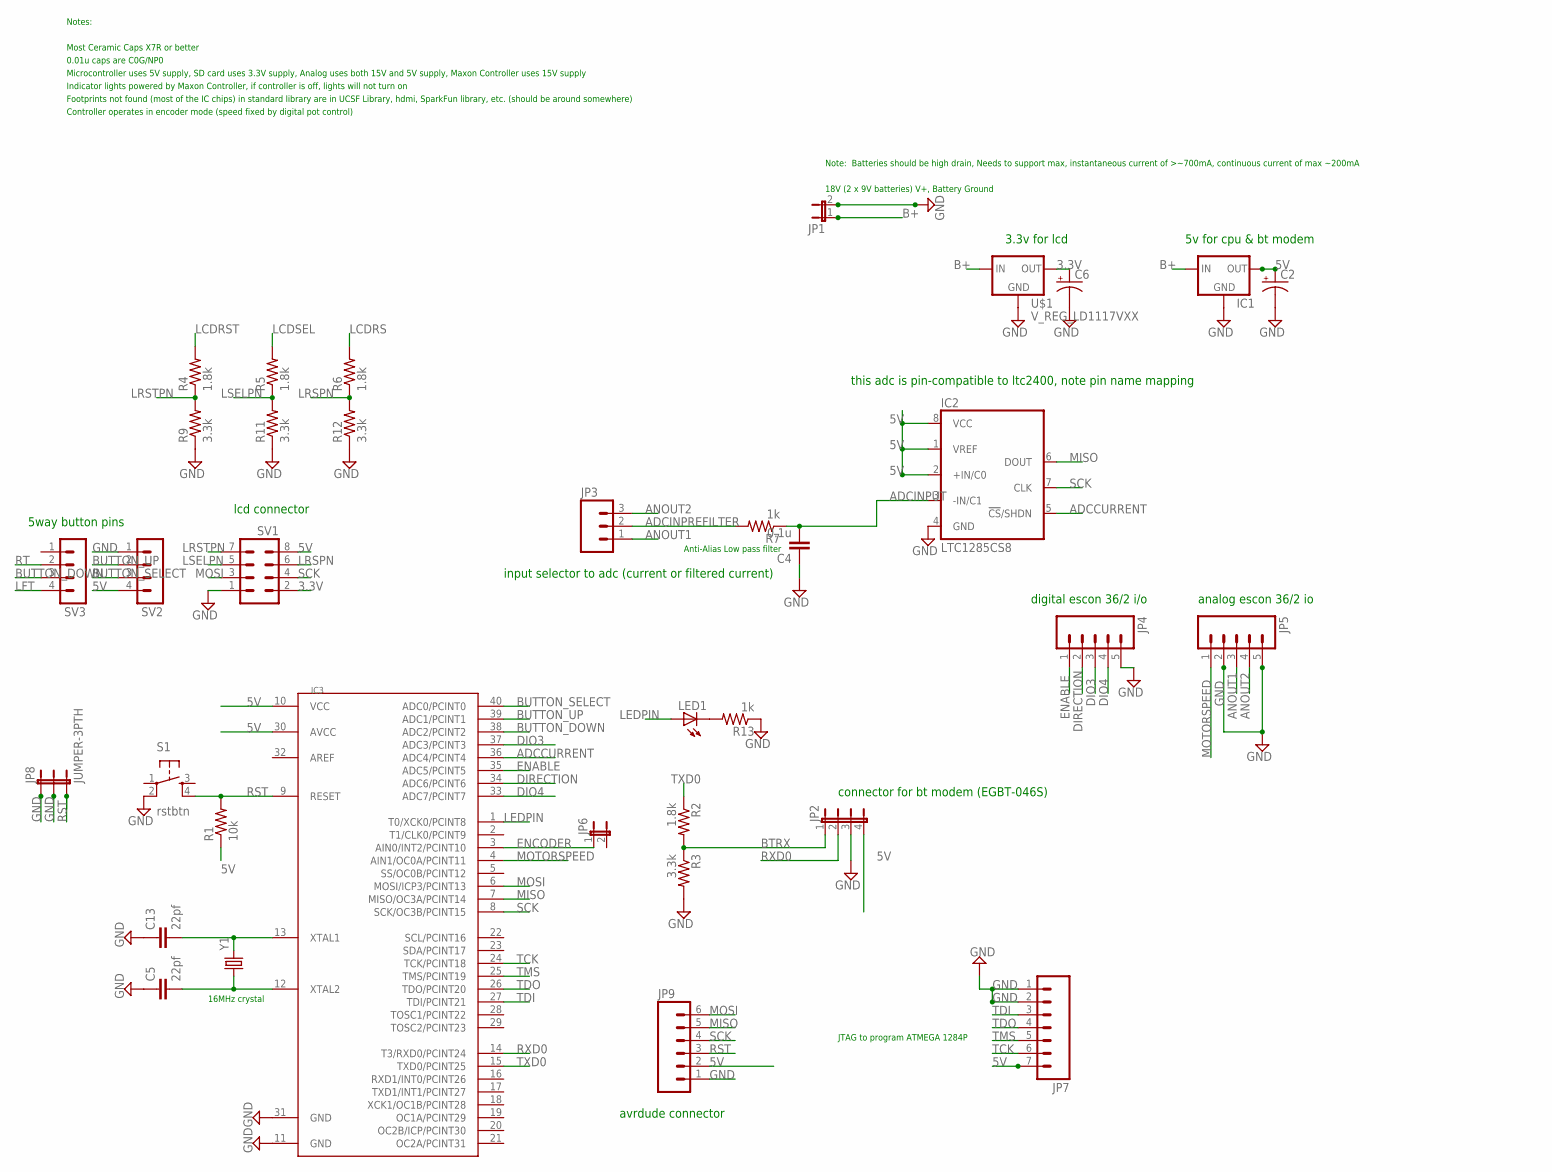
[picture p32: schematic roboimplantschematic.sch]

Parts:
C2, C6: CAP_POLPTH2; CPOL-RADIAL-10UF-25V
C4: 0.1u; 050X030_025
C5, C13: 22pf; 050X030_025
IC1: V_REG_78XX-TO-220; TO-220-ALT
IC2: LTC1285CS8; SOIC8
IC3: MEGA1284P; DIL40
JP1: JP1E; JP1
JP2: JP4E; JP4
JP3: M03LOCK_LONGPADS; 1X03_LOCK_LONGPADS
JP4, JP5: M05PTH_LONGPADS; 1X05_LONGPADS
JP6: JUMPER-2PTH; 1X02
JP7: M07LOCK; 1X07_LOCK
JP8: JUMPER-3PTH; 1X03
JP9: M06SIP_LOCK; 1X06-SIP_LOCK
LED1: LED5MM
R1: 10k; 0204/7
R2, R4, R5, R6: 1.8k; 0207/2V
R3, R9, R11, R12: 3.3k; 0207/2V
R7, R13: 1k; 0207/2V
S1: rstbtn; TACTILE-PTH
SV1: MA04-2
SV2, SV3: MA04-1
U$1: V_REG_LD1117VXX; 78XXL
Y1: CRYSTALHC49US; HC49US

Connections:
3.3V: C6.1 (+), SV1.2, U$1.GND (OUT)
5V: C2.1 (+), IC1.OUT, IC2.1 (VREF), IC2.2 (+IN/C0), IC2.8 (VCC), IC3.10 (VCC), IC3.30 (AVCC), JP2.4, JP7.7, JP9.2, R1.1, SV1.8, SV2.4
ADCCURRENT: IC2.5 (!CS!/SHDN), IC3.36 (ADC4/PCINT4)
ADCINPREFILTER: JP3.2, R7.2
ADCINPUT: C4.2, IC2.3 (-IN/C1), R7.1
ANOUT1: JP3.1, JP5.3
ANOUT2: JP3.3, JP5.4
B+: IC1.IN, JP1.1, U$1.OUT (IN)
BTRX: JP2.1, R2.2, R3.1
BUTTON_DOWN: IC3.38 (ADC2/PCINT2), SV3.3
BUTTON_SELECT: IC3.40 (ADC0/PCINT0), SV2.3
BUTTON_UP: IC3.39 (ADC1/PCINT1), SV2.2
DIO3: IC3.37 (ADC3/PCINT3), JP4.3
DIO4: IC3.33 (ADC7/PCINT7), JP4.4
DIRECTION: IC3.34 (ADC6/PCINT6), JP4.2
ENABLE: IC3.35 (ADC5/PCINT5), JP4.1
ENCODER: IC3.3 (AIN0/INT2/PCINT10), JP6.1
GND: C2.2 (-), C4.1, C5.1, C6.2 (-), C13.1, IC1.GND, IC2.4 (GND), IC3.11 (GND), IC3.31 (GND), JP1.2, JP2.3, JP4.5, JP5.2, JP5.5, JP7.1, JP7.2, JP8.1, JP8.2, JP9.1, R3.2, R9.1, R11.1, R12.1, R13.1, S1.2, SV1.1, SV2.1, U$1.IN (GND)
LCDRS: R6.2
LCDRST: R4.2
LCDSEL: R5.2
LEDPIN: IC3.1 (T0/XCK0/PCINT8), LED1.A
LFT: SV3.4
LRSPN: R6.1, R12.2, SV1.6
LRSTPN: R4.1, R9.2, SV1.7
LSELPN: R5.1, R11.2, SV1.5
MISO: IC2.6 (DOUT), IC3.7 (MISO/OC3A/PCINT14), JP9.5
MOSI: IC3.6 (MOSI/ICP3/PCINT13), JP9.6, SV1.3
MOTORSPEED: IC3.4 (AIN1/OC0A/PCINT11), JP5.1
unnamed: C5.2, IC3.12 (XTAL2), Y1.1
unnamed: C13.2, IC3.13 (XTAL1), Y1.2
unnamed: LED1.K (C), R13.2
RST: IC3.9 (RESET), JP8.3, JP9.3, R1.2, S1.4
RT: SV3.2
RXD0: IC3.14 (T3/RXD0/PCINT24), JP2.2
SCK: IC2.7 (CLK), IC3.8 (SCK/OC3B/PCINT15), JP9.4, SV1.4
TCK: IC3.24 (TCK/PCINT18), JP7.6
TDI: IC3.27 (TDI/PCINT21), JP7.3
TDO: IC3.26 (TDO/PCINT20), JP7.4
TMS: IC3.25 (TMS/PCINT19), JP7.5
TXD0: IC3.15 (TXD0/PCINT25), R2.1

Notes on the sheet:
18V (2 x 9V batteries) V+, Battery Ground
JTAG to program ATMEGA 1284P
Most Ceramic Caps X7R or better
Notes:
0.01u caps are C0G/NP0
Anti-Alias Low pass filter
Microcontroller uses 5V supply, SD card uses 3.3V supply, Analog uses both 15V and 5V supply, Maxon Controller uses 15V supply
Indicator lights powered by Maxon Controller, if controller is off, lights will not turn on
Footprints not found (most of the IC chips) in standard library are in UCSF Library, hdmi, SparkFun library, etc. (should be around somewhere)
16MHz crystal
Note: Batteries should be high drain, Needs to support max, instantaneous current of >~700mA, continuous current of max ~200mA
Controller operates in encoder mode (speed fixed by digital pot control)
connector for bt modem (EGBT-046S)
digital escon 36/2 i/o
analog escon 36/2 io
input selector to adc (current or filtered current)
3.3v for lcd
5v for cpu & bt modem
this adc is pin-compatible to ltc2400, note pin name mapping
lcd connector
5way button pins
avrdude connector

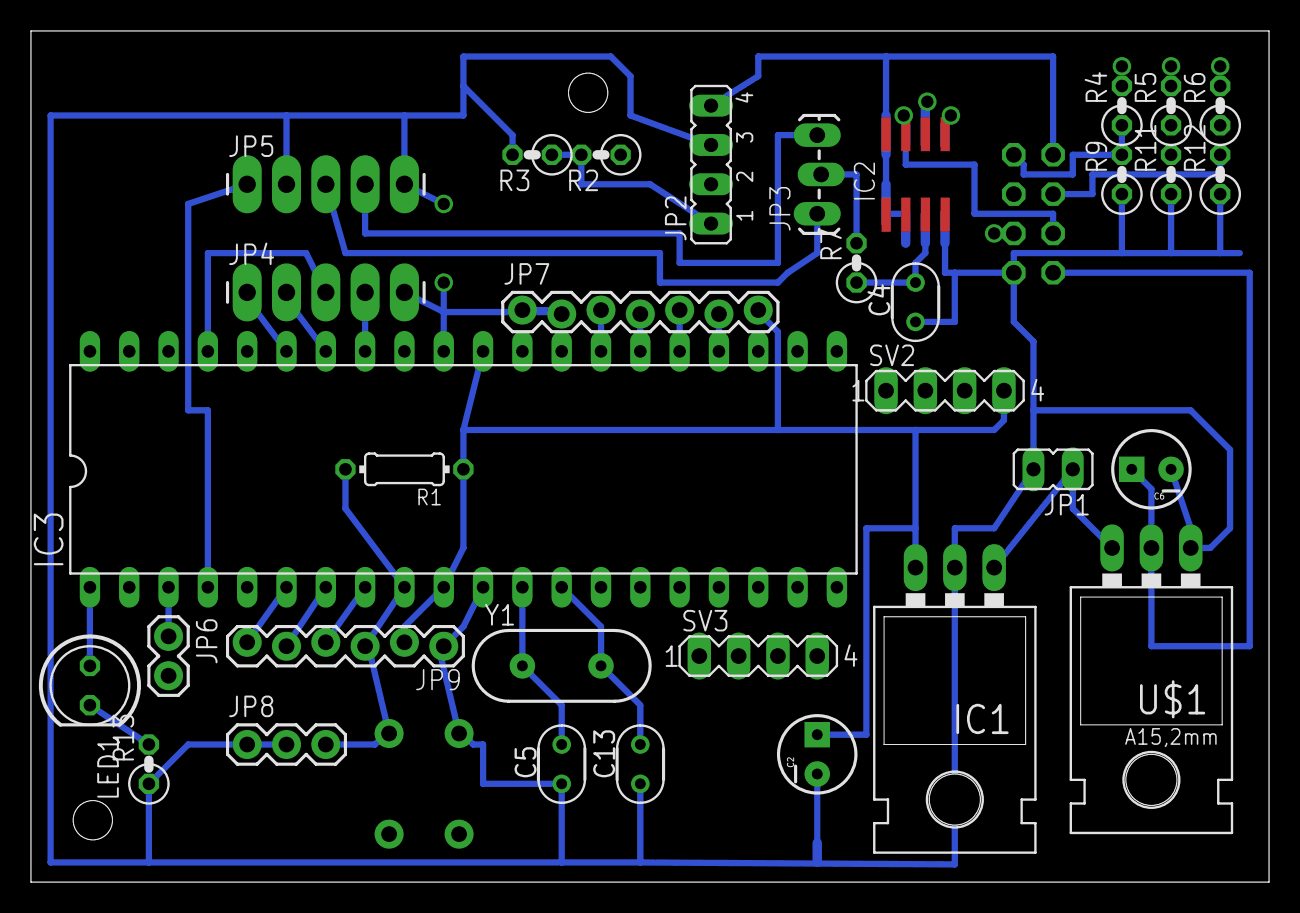
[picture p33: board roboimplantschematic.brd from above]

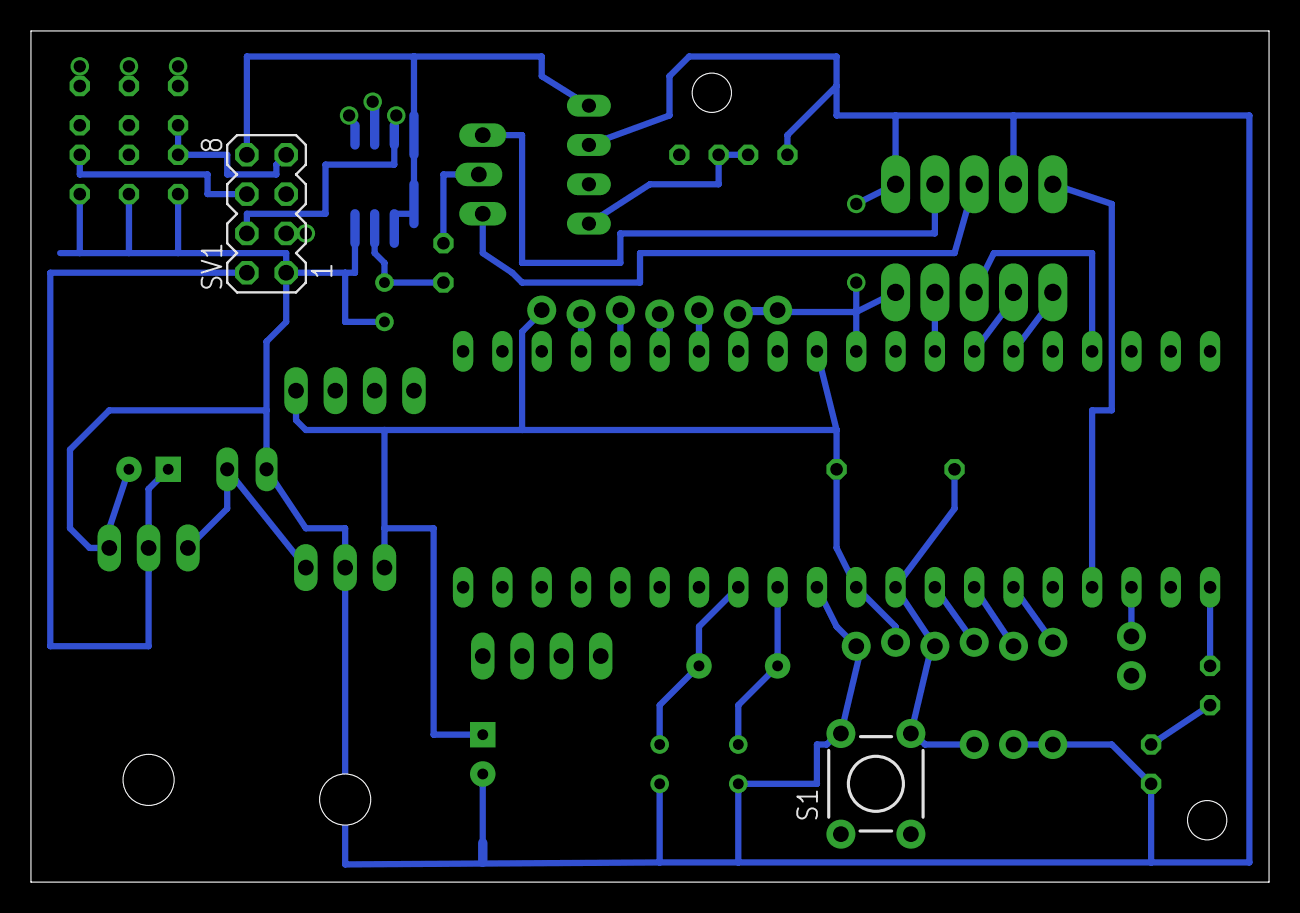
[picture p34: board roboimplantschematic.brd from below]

Board: 2 copper layers, 80.0 x 55.0 mm, 35 parts (2 on the bottom side), 36 nets.

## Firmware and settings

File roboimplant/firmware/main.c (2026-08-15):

/*
 * GccApplication1.c
 *
 * Created: 8/18/2012 12:49:39 PM
 *  Author: arie
 */ 

 
//#define F_CPU 20000000

#include <avr/io.h>
#include <util/delay.h>
#include <avr/interrupt.h>
#include <stdio.h>
#include <ctype.h>
#include <string.h>
#include "utils.h"
#include "stdiodefs.h"
#include "uart.h"
#include "printFloat.h"
#include "pwm.h"
#include "adc.h"
#include "adc_ad7715.h"
#include "spi.h"
#include "digitalPot.h"
#include "config.h"
#include "messageDispatcher.h"
#include "sdcard/sd_routines.h"
#include "power.h"
#include "parallax5waybutton.h"
#include <stdlib.h>
#include "calibration.h"

PhysicalParamsBlock phyParams;
CommandParams cmdParams;
DebugParams dbgParams;
CalibrationParams calibParams;
ProcedureParams procedureParams;

//this is a quick hack to support the parallax 5 way joystick
#define MOTOR_STOPPED   0
#define MOTOR_CW        1
#define MOTOR_CCW       2
int motorMode=0;

 
//redirect the standard output stream to BT uart and and error stream to rs232 uart
static FILE mystderr = FDEV_SETUP_STREAM(uart_putchar, NULL, _FDEV_SETUP_WRITE);
#ifdef USE_RS232_UART
  static FILE mystdout = FDEV_SETUP_STREAM(uart_putchar, NULL, _FDEV_SETUP_WRITE);
#else
  static FILE mystdout = FDEV_SETUP_STREAM(uart1_putchar, NULL, _FDEV_SETUP_WRITE);
#endif

#ifdef USE_RS232_UART
  #define COMMAND_INPUT_FUNCTION  uart_getc
#else
  #define COMMAND_INPUT_FUNCTION  uart1_getc
#endif

void setDefaultParamValues()
{
  //physical parameters initial values
  phyParams.motorSpeed = HALTING_SPEED_VALUE; //half way between 0 and 255
  phyParams.torqueConstant = TORQUE_CONSTANT;
  phyParams.speedConstant = SPEED_CONSTANT;

  //Debug related parameters
  dbgParams.duplicateInputToStdErr = TRUE;
  dbgParams.sendPeriodicUpdates = FALSE;
  dbgParams.updateFrequencyMsec = DATA_UPDATE_INTERVAL;  
  
  resetCounters();
}

void initTimers(void)
{
 
    // initialize Timer1
    cli();          // disable global interrupts
    TCCR2A = 0;     // set entire TCCR2A register to 0
    TCCR2B = 0;     // same for TCCR2B

    //Nominal period = 1/16000000
    //Prescaling x N makes the period N/16000000
    //By providing the value of OCR2A, we get a period between interrupts to OCR2A*N/16000000 = (250*64/16000000) = 1.024ms.
    //If we want interrupt every second, we would get 
    // set compare match register to desired timer count:
    OCR2A = 250; 
    // turn on CTC mode:
    TCCR2A |= (1 << WGM21);
    //  64 prescaler: (see page 155 in the full manual of 1284p)
    TCCR2B |= (1 << CS22);//|(1 << CS20);//|(1 << CS20);
    // enable timer compare interrupt:
    TIMSK2 |= (1 << OCIE2A);
    sei();          // enable global interrupts
}


void enableExternalInterrupts(void)
{
  sei();

  //enable interrupts
  // details for this can be seen here : https://coefs.uncc.edu/sjkuyath/files/2012/04/Topic_16.pdf
  EICRA=EICRA|0b00110000;     //Turn on spin counter, enables INT2 trigger  , interrupt on high for a rising edge
  EIMSK=EIMSK|0b00000100;     //Enable interrupt 0x2

  cbi(DDRB,DDB2); 
  cbi(PORTB,PORTB2);
}

void initGeneralSettings(void)
{
  //do this first since there are some critical stuff there
  //initPower();

	stdout = &mystdout; //Required for printf init	
	stderr = &mystderr; //Required for printf init	

  memset(&phyParams,0,sizeof(PhysicalParamsBlock));
  memset(&cmdParams,0,sizeof(CommandParams));
  memset(&dbgParams,0,sizeof(DebugParams));
  memset(&calibParams,0,sizeof(CalibrationParams));
  memset(&procedureParams,0,sizeof(ProcedureParams));

  setDefaultParamValues();

  initTimers();

  SPI_Init();  

  enableExternalInterrupts();

  //set the PA5 and PA6 pins as digital outputs that feed into the escon 36/2 dc controller
  //enable the motor controller
  sbi(DDRA,PORTA5);
  //direction : 1 = cw , 0 =ccw
  sbi(DDRA,PORTA6);
}


void initUart(void)
{
	/*
     *  Initialize UART library, pass baudrate and AVR cpu clock with the macro 
     *  UART_BAUD_SELECT() (normal speed mode ) or 
     *  UART_BAUD_SELECT_DOUBLE_SPEED() ( double speed mode)
     */
    uart_init( UART_BAUD_SELECT(UART_BAUD_RATE,F_CPU) ); 

    //Init the second uart (has a bluesmirf bluetooth modem)
    uart1_init( UART_BAUD_SELECT(UART_BAUD_RATE,F_CPU) ); 
    
    // now enable interrupt, since UART library is interrupt controlled
    sei();
	  printf("UART inited\n");
	
}

void initSDCard(void)
{
#ifdef USE_SDCARD //only if we compile with this option (save precious flash space)
  int error=0;
  for (int i=0; i<3; i++)
  {
    fprintf(stderr,"About to init SD card, attempt #%d\n",(i+1));
    error = SD_init();
    if(!error) 
    {
      dbgParams.sdcardAvailable = TRUE;
      SD_displayCardInfo(stderr); 
      writeFileFromBuffer("file1.txt","abcdefghijklmnop",strlen("abcdefghijklmnop"));
      break;
    }
  }

  if(error)
  {
    if(error == 1)  
      fprintf(stderr,"SD card not detected..\n");
    if(error == 2)  
      fprintf(stderr,"Card Initialization failed..\n");
  }
#endif

}


//This function is called periodically to sample the physical state of the system
//and updates the corresponding phyParams structure
void updateMeasurements(void)
{
    float voltage=0.0f,current=0.0f;
    if (measureVoltage(&voltage))
    {
      updateVoltageStatistics(voltage);
    }
     else 
     {
      //fprintf(stderr,"Invalid voltage  value detected on the ADC - debug this !!\n");
     }

    if( measureCurrent(&current))
    {
      updateCurrentStatistics(current);
    
      bool coupledBefore = phyParams.isCoupled;    
      phyParams.isCoupled = (fabs(phyParams.currentAmplitude) > COUPLING_THRESHOLD_CURRENT);
      //fprintf(stderr,"CoupledBefore: %d, coupledNow : %d\n",coupledBefore,phyParams.isCoupled);
      if (coupledBefore && !phyParams.isCoupled)
      {
         fprintf(stderr,"Coupling lost, not counting spins till coupling is reestablished\n");
         procedureParams.lostCoupling=TRUE;
         notifyCoupling(FALSE);
      }

      if (!coupledBefore && phyParams.isCoupled)
      {
         fprintf(stderr,"coupling reestablished, counting spins again\n");
         procedureParams.establishedCoupling=TRUE;
        notifyCoupling(TRUE);
      }
     }
     else 
     {
      //fprintf(stderr,"\nInvalid current value detected on the ADC - debug this !!\n");
     }
    
   
    //compute the angular speed : number of spins during the last sampling interval 
    float periodInSeconds = (float)ADC_SAMPLE_INTERVAL/(float)TIME_COUNTS_IN_ONE_SEC;
    phyParams.angularSpeed = (float)(phyParams.spinCount - phyParams.previousSpinCount)/periodInSeconds;
    //fprintf(stderr,"dspin = %d , Angspeed:",(phyParams.spinCount-phyParams.previousSpinCount));
    //printFloat(phyParams.angularSpeed,4,stderr);
    //NEWLINE_STDERR;
    phyParams.previousSpinCount = phyParams.spinCount;

    phyParams.estimatedSpeedConstant = 60*phyParams.angularSpeed/phyParams.voltage;
}


//monitor uart input and perform action according to the commands
void processCommandInput(void)
{
    unsigned char mychar;
    int status;
		unsigned int cc = uart_getc();//COMMAND_INPUT_FUNCTION(); 
    bool isRepeat=FALSE;
		if ( cc & UART_NO_DATA || cc&0xFF00 )
		{
		}	
		else
		{
      mychar = (unsigned char)cc;
      //for debug purposes
      if (dbgParams.duplicateInputToStdErr)
      {
        fprintf(stderr,"%c",cc); 
        fprintf(stdout,"%c",cc); 
      }


      if (mychar==13)
      { 
        cmdParams.cmdBuffer[cmdParams.cmdPosition]=0;      //terminate the string and process the command

        fprintf(stderr,"Dispatching: %s\n",cmdParams.cmdBuffer);
        status=dispatchMessage(cmdParams.cmdBuffer,&phyParams,&cmdParams,&dbgParams,&calibParams,&procedureParams,&isRepeat);
        
        cmdParams.cmdPosition=0;                    //reset the command buffer
        //fprintf(stderr,"\nready for next command \n");
        if (!status)
          fprintf(stderr,"OK\n");
        else
          fprintf(stderr,"ERROR\n");
 
        if (!isRepeat)  
          strcpy(cmdParams.previousCommand,cmdParams.cmdBuffer);

        memset(cmdParams.cmdBuffer,0,MAX_CMD_LEN);
        //printf("\nready for next command \n");
        
      }
      else if (cmdParams.cmdPosition<MAX_CMD_LEN)
      {
        cmdParams.cmdBuffer[cmdParams.cmdPosition] = mychar;
        cmdParams.cmdPosition++;  
      }
   }
}

void updateProcedureState(void)
{
  if (procedureParams.procedureTerminated)
  {
    fprintf(stderr,"btterminated %lu %lu %lu\n",procedureParams.startTime,procedureParams.stopTime,procedureParams.targetSpinCounts);
    fprintf(stderr,"--------------------->Procedure Terminated");
    procedureParams.procedureTerminated=FALSE;
    adjustSpeed(0);
    turnMotorOff();
  }  
}


void processPanelInput(void)
{
  byte buttons=0x0;
  buttons = buttonsPressed();
  bool isRepeat=FALSE;
  if (buttons & PUSH_DOWN)
  {
    waitUntilReleased(PUSH_DOWN);
    fprintf(stderr,"DOWN pressed\n");
    //incrementSettingNumber();
//    dispatchMessage("atdec",&phyParams,&cmdParams,&dbgParams,&calibParams,&procedureParams,&isRepeat);
    //displaySetting(&procedureParams);
    decreaseSpeed(3,&phyParams);
    blink(2);
  
  }
  if (buttons & PUSH_UP)
  {
    waitUntilReleased(PUSH_UP);
    fprintf(stderr,"UP pressed\n");
  //  dispatchMessage("atinc",&phyParams,&cmdParams,&dbgParams,&calibParams,&procedureParams,&isRepeat);
    increaseSpeed(3,&phyParams);
    blink(2);
    //decrementSettingNumber();
    //displaySetting(&procedureParams);
  }
 
  if (buttons & PUSH_RIGHT)
  {
    fprintf(stderr,"RIGHT pressed\n");
    waitUntilReleased(PUSH_RIGHT);
    increaseSpeed(3,&phyParams);
    blink(1);
 }
 
  if (buttons & PUSH_LEFT)
  {
    fprintf(stderr,"LEFT pressed\n");
    waitUntilReleased(PUSH_LEFT);
    decreaseSpeed(3,&phyParams);
    blink(2);
  }

  if (buttons &PUSH_SELECT)
  {
    fprintf(stderr,"SELECT pressed\n");
    waitUntilReleased(PUSH_SELECT);
 
    motorMode=(motorMode+1)%3;

    switch (motorMode)
    {
      case MOTOR_STOPPED:
      {
        phyParams.motorSpeed=HALTING_SPEED_VALUE;
        adjustSpeed(phyParams.motorSpeed);
        turnMotorOff();
        break;
      }
      case MOTOR_CW:
      {
          phyParams.motorSpeed=HALTING_SPEED_VALUE;
          adjustSpeed(phyParams.motorSpeed);
          cbi(PORTA,PA6);
          blink(1);
          turnMotorOn();
          break;
      }
      case MOTOR_CCW:
      {
          phyParams.motorSpeed=HALTING_SPEED_VALUE;
          adjustSpeed(phyParams.motorSpeed);
          sbi(PORTA,PA6);
          blink(2);
          turnMotorOn();
          break;
      }
    } 
    fprintf(stderr,"Shifted dir to %d\n",motorMode);
  }


}

int main(void)
{
  //there is a short in the signal conditioning board (when i connect only 12v vcc to it, i see that the ground, although should be floating
  // it is also ~ 12v, sometimes even higher than my vcc voltage) 
  // for this reason, the first thing i do - i turn on the power mosfet and give power (provide path to the ground) for the signal conditioning board.
  // Once i do that it settles since the resistance from true ground is way smaller so the smaller resistor wins. Ask Mozzi, how to debug this.
  blink(2);
  initPower(); 
	initGeneralSettings();
  initUart();

  fprintf(stderr,"stderr\n");
  fprintf(stdout,"stdout\n");

  initParallax5WayButton();
  //testParallax5WayButton(stderr);

  initPWM();

  initDigitalPot();
  blink(2);
  //testDigitalPot(0x10); 

  initADC();
  //initSDCard();

#if 0
  while (1)
  {
    processCommandInput();
    //testUartInLoopback();
  }
#endif  

  //initCalibration();

  //testADC(0);

	//fprintf(stderr,"Entering uart echo mode\n");
  //while (1)
  //{
  //  testUartInLoopback();
  //}

  int iterationCounter=0;
   

	blink(2);
  while (1)
  {

    processCommandInput();
    processPanelInput();
    iterationCounter++;
    //the ISR signals us once every X milliseconds to resample the system's state
    if (phyParams.shouldSample)
    {  
       //fprintf(stdout,"Sampling time..................................................................\n");
       updateMeasurements();
       //testADCSingleIteration();
       phyParams.shouldSample=FALSE;
    }

    if ( dbgParams.sendPeriodicUpdates && dbgParams.shouldSendUpdate)
    {
      sendUpdates(stderr);
      sendUpdates(stdout);
    }
    
    updateProcedureState();

  }
}

void resetCounters(void)
{
  phyParams.current=0.0;
  phyParams.maxCurrent=0.0;
  phyParams.minCurrent=100000.0;
  phyParams.currentAmplitude=0.0;
  phyParams.ncurrentSamples=0;

  phyParams.voltage=0.0;
  phyParams.minVoltage=100000.0;
  phyParams.maxVoltage=0;
  phyParams.voltageAmplitude=0.0;
  phyParams.nvoltageSamples=0;

  phyParams.isCoupled=FALSE;
}

//this is time-critical and cannot wait for next update. need to send message now !!
void notifyCoupling(bool established)
{
   if (established)
   {
      fprintf(stdout,"btestablishedcoupling\n");
      fprintf(stderr,"btestablishedcoupling\n");
   }
   else
   {
      fprintf(stdout,"btlostcoupling\n");
      fprintf(stderr,"btlostcoupling\n");
   } 

}

//send periodic updates to the console (whoever is listening on the other side of rs232
void sendUpdates(FILE* stream)
{
      dbgParams.shouldSendUpdate=FALSE;
      //int currentValue = (int)(scalingFactor * sin(2.0*3.1416*0.01*(double)msgcnt++));
      //int voltageValue = (int)(scalingFactor * sin(2.0*3.1416*0.01*(double)msgcnt++));
      fprintf(stream,"btcurrent %d %d\n",(int)(phyParams.current*SCALING_FACTOR),SCALING_FACTOR);
      fprintf(stream,"btcurrentamplitude %d %d\n",(int)(phyParams.currentAmplitude*SCALING_FACTOR),SCALING_FACTOR);
      //fprintf(stream,"btvoltage %d %d\n",(int)(phyParams.voltage*SCALING_FACTOR),SCALING_FACTOR);
      //fprintf(stream,"btvoltageamplitude %d %d\n",(int)(phyParams.voltageAmplitude*SCALING_FACTOR),SCALING_FACTOR);
      fprintf(stream,"btspincount %lu\n",phyParams.spinCount);
      //angular speed sent in rpm
      unsigned long int speedRpm = abs ( (unsigned long int) (60*phyParams.angularSpeed));
      fprintf(stream,"btangularspeed %lu %d\n",speedRpm,1);  
      fprintf(stream,"btmseccounter %lu\n",phyParams.msecCounter);

      if (procedureParams.isInProcedure)
      {
         fprintf(stream,"btremaining %lu %lu\n",procedureParams.spinCountsRemaining,procedureParams.targetSpinCounts);
      }

      //debug printouts      
      //fprintf(stderr,"btspincount %lu\n",phyParams.spinCount);
      

      /*fprintf(stderr,"Motor Voltage : ");
      printFloat(phyParams.voltage,6,stderr);
      fprintf(stderr,"\n");

      fprintf(stderr,"Motor Current : ");
      printFloat(1000*phyParams.current,2,stderr);
      fprintf(stderr," [mA]\n");

      fprintf(stderr,"Angular Speed: ");
      printFloat(60*phyParams.angularSpeed,3,stderr);
      fprintf(stderr," RPM\n");*/

      //fprintf(stderr,"Estimated speed constant: ");
      //printFloat(phyParams.estimatedSpeedConstant,6,stderr);
      //NEWLINE_STDERR;

      //fprintf(stderr,"IsInProcedure : %d\n",procedureParams.isInProcedure);
      //fprintf(stderr,"remaining out of total : %lu/%lu\n",procedureParams.spinCountsRemaining,procedureParams.targetSpinCounts);

}

void updateVoltageStatistics(float voltage)
{
      phyParams.voltage = voltage;
      int thisIndex = phyParams.nvoltageSamples%AVG_HISTORY_LENGTH;
      phyParams.voltageSamples[thisIndex]=voltage;

      phyParams.maxVoltage = MAX(phyParams.voltage,phyParams.maxVoltage);
      phyParams.minVoltage = MIN(phyParams.voltage,phyParams.minVoltage);
      //phyParams.voltageAmplitude = fabs( (phyParams.maxVoltage - phyParams.minVoltage)/2.0 ) ;
      //phyParams.voltageAmplitude = (HISTORY_AVG_WEIGHT*phyParams.voltageAmplitude*(phyParams.nvoltageSamples-1)+(1.0-HISTORY_AVG_WEIGHT)*phyParams.voltage)/phyParams.nvoltageSamples;
      
      phyParams.voltageAmplitude=0.0f;
      //right now deal only with the case of full populated array
      if (phyParams.nvoltageSamples>AVG_HISTORY_LENGTH)
      {
        int weight=AVG_HISTORY_LENGTH;
        //go backwards in a circular fashion and compute the weighted average
        for (int i=thisIndex;i>=0;i--)
        {
           phyParams.voltageAmplitude += phyParams.voltageSamples[i]*weight;
           weight--;
        }
        for (int i=AVG_HISTORY_LENGTH-1;i>thisIndex;i--)
        {
           phyParams.voltageAmplitude += phyParams.voltageSamples[i]*weight;
           weight--;
        }
        int totalWeight = (AVG_HISTORY_LENGTH*(AVG_HISTORY_LENGTH+1))/2;
        phyParams.voltageAmplitude /= totalWeight;
      }
      phyParams.nvoltageSamples++;

}


void updateCurrentStatistics(float current)
{
      phyParams.current = current;
      int thisIndex = phyParams.ncurrentSamples%AVG_HISTORY_LENGTH;
      phyParams.currentSamples[thisIndex]=current;
      int icurrent=(int)(1000*phyParams.current);
      //fprintf(stderr,"current : %d ma will go into index#%d\n",icurrent,thisIndex);
      phyParams.maxCurrent = MAX(phyParams.current,phyParams.maxCurrent);
      phyParams.minCurrent = MIN(phyParams.current,phyParams.minCurrent);
      //phyParams.currentAmplitude = fabs ( (phyParams.maxCurrent - phyParams.minCurrent)/2.0 );
      //phyParams.currentAmplitude = (HISTORY_AVG_WEIGHT*phyParams.currentAmplitude*(phyParams.ncurrentSamples-1)+(1.0-HISTORY_AVG_WEIGHT)*phyParams.current)/phyParams.ncurrentSamples;

      phyParams.currentAmplitude=0.0f;
      //right now deal only with the case of full populated array
      if (phyParams.ncurrentSamples>AVG_HISTORY_LENGTH)
      {
        int weight=AVG_HISTORY_LENGTH;
        //go backwards in a circular fashion and compute the weighted average
        for (int i=thisIndex;i>=0;i--)
        {
           phyParams.currentAmplitude += phyParams.currentSamples[i]*weight;
           //fprintf(stderr,"Adding %d ma with weight %d from place %d, totalCurrent=%d ma\n",(int)(1000*phyParams.currentSamples[i]),weight,i,(int)(1000*phyParams.currentAmplitude));
              
           weight--;
        }
        for (int i=AVG_HISTORY_LENGTH-1;i>thisIndex;i--)
        {
           phyParams.currentAmplitude += phyParams.currentSamples[i]*weight;
           //fprintf(stderr,"Adding %d ma with weight %d from place %d, totalCurrent=%d ma\n",(int)(1000*phyParams.currentSamples[i]),weight,i,(int)(1000*phyParams.currentAmplitude));
           weight--;
        }
        int totalWeight = (AVG_HISTORY_LENGTH*(AVG_HISTORY_LENGTH+1))/2;
        //fprintf(stderr,"total current is %d ma, totalWeight : %d\n",(int)(1000*phyParams.currentAmplitude),totalWeight);
        phyParams.currentAmplitude /= totalWeight;
       
      }
      phyParams.ncurrentSamples++;

}




//This is a sample ISR that occurs on a timer overflow event (not in CTC mode)
ISR(TIMER2_OVF_vect)
{
	//phyParams.timecount++;
}

ISR(INT2_vect)
{
	phyParams.spinCount++;				//Increment turns count

  if (procedureParams.isInProcedure && phyParams.isCoupled)
  {
    procedureParams.spinCountsRemaining--;
    if (procedureParams.spinCountsRemaining==0)
    {
      procedureParams.isInProcedure = FALSE;
      procedureParams.stopTime = phyParams.msecCounter;
      procedureParams.procedureTerminated=TRUE;
    }
  }
}

//byte value = 1;
ISR(TIMER2_COMPA_vect)
{
   //To test how often this ISR is called, i toggle PORTB pins
   //PORTB = value;
   //value = 1-value;
   phyParams.msecCounter++;
   if (phyParams.msecCounter%ADC_SAMPLE_INTERVAL==0)
      phyParams.shouldSample = TRUE;
   
   if (phyParams.msecCounter%DATA_UPDATE_INTERVAL==0)
      dbgParams.shouldSendUpdate = TRUE;
    

}

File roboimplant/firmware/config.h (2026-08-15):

#ifndef ROBOIMPLANT_CONFIG_H
#define ROBOIMPLANT_CONFIG_H

#include <avr/io.h>
#include <stdio.h>
#include <util/delay.h>
#include <avr/interrupt.h>


//Maximum length for a command sent over UART
#define MAX_CMD_LEN 256
#define TRUE        1
#define FALSE       0
// to avoid dealing with floats, i scale everything by this factor when data exchanging with the console
#define SCALING_FACTOR 1000

//some useful macros
#define MIN(a,b) (((a)<(b))?(a):(b))
#define MAX(a,b) (((a)>(b))?(a):(b))

//Set bit in IO port 
#define sbi(port, bit) (port) |= (1 << (bit))

//Clear \c bit in IO port \c port.
#define cbi(port, bit) (port) &= ~(1 << (bit))



// units mNm/A
#define TORQUE_CONSTANT   (23.5)  

// units rpm/V
#define SPEED_CONSTANT    (406.0) 

//threshold above which, the motor is considered coupled to the implant
#define COUPLING_THRESHOLD_CURRENT (0.035)

#define HIGH_SPEED          255
#define LOW_SPEED           0

//How many rotations do we need to make to shift the rod by 1mm.
//#define MM_TO_ROTATIONS_FACTOR    (1024.0*20.0)
#define MM_TO_ROTATIONS_FACTOR    (1.0)


// this is the resistance value that leads to speed effectively 0
#define HALTING_SPEED_VALUE   110

#define CLOCK_WISE          0
#define COUNTER_CLOCK_WISE  1

// how many time counts (timer#2 interrupts) occurs in a single second (this might be 1024 to be more precise)
#define TIME_COUNTS_IN_ONE_SEC   (1000)

//how often (in msec) should we update the console about the state of the system
#define DATA_UPDATE_INTERVAL    2500

//for cumulative moving average (alpha*old_average + (1-alpha)*new_sample)
#define HISTORY_AVG_WEIGHT    0.5

//Auxiliary type declarations
typedef uint8_t byte;
typedef uint8_t bool;
typedef volatile float vfloat;
typedef volatile int vint;

#define AVG_HISTORY_LENGTH    10

//This struct describes the physical parameters of the system,
//such as the different mechanical/electrical state variables
//that are periodically sampled (or computed)
typedef struct _params_block
{
  volatile int motorSpeed;
  volatile float voltage;
  volatile float maxVoltage;
  volatile float minVoltage;
  volatile float voltageAmplitude;

  volatile float current;
  volatile float maxCurrent;
  volatile float minCurrent;
  volatile float currentAmplitude;

  //how many turns of the motor have we witnessed
  volatile long int spinCount;
  volatile long int previousSpinCount;

  //counts the time ticks using the timer interrupt mechanism.
  //due to 16mhz clock, each interrupt actulaly occurs every 1.024 msec - this is why J.L. used 32khz external crystal
  volatile unsigned long int msecCounter;

  //this is a flag turned by the timer ISR indicating that the period between adc samples has elapsed.
  volatile bool shouldSample;

  //Those are characteristic values of the motor that allow translating speed and torque from voltage and current
  volatile double torqueConstant;
  volatile double speedConstant;

  //Is the implant coupled to the motor at a given time (measured via current thresholding)
  volatile bool isCoupled;
  
  //are we going cw or ccw
  volatile byte rotationDirection;


  //angular speed in RPS (rounds per second)
  volatile float angularSpeed;

  //dividing the speed by the voltage, we can try and see how our estimate does with the spec
  volatile float estimatedSpeedConstant;

  volatile int ncurrentSamples;
  volatile float currentSamples[AVG_HISTORY_LENGTH];

  volatile int nvoltageSamples;
  volatile float voltageSamples[AVG_HISTORY_LENGTH];

} PhysicalParamsBlock;


//This struct describes the  parameters of the interaction between the user
//and the console (typically over a uart serial port BT/RS232)
typedef struct _command_param_block
{
  //This buffer contains the command that user sends to us over uart
  char previousCommand[MAX_CMD_LEN];
  char cmdBuffer[MAX_CMD_LEN];
  //current position inside the command buffer
  int cmdPosition;
}
CommandParams;

//this struct aggregates all the different calibration parameters
typedef struct _calibration_param_block
{
  //motor voltage on low speed setting
  float lowSpeedVoltage;
  //motor voltage on high speed setting
  float highSpeedVoltage;
  
  //motor current without any load
  float noloadCurrent;
  //moto current when loaded with implant
  float loadedCurrent;

  //motor current during low and high speeds
  float lowSpeedCurrent;
  float highSpeedCurrent;

  //what percentage of the loadedCurrent should be considered coupled
  float currentThresholdPercentage;  
}
CalibrationParams;


//This struct aggregates all the different debug related parameters
typedef struct _debug_param_block
{
  bool duplicateInputToStdErr;
  bool sendPeriodicUpdates;
  bool sdcardAvailable;
  bool shouldSendUpdate;
  //how often should we send an update
  int updateFrequencyMsec;
  char currentTime[30];
}
DebugParams;
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

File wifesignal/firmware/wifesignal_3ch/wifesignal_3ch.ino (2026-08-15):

/*
 * WifeSignal - 3-channel BLE firmware (Rev A PCB)
 * Board:  ESP32-C3 SuperMini Plus (ESP32C3 Dev Module, USB CDC On Boot = Enabled)
 * BLE:    NimBLE-Arduino v2.x
 *
 * One STATE byte drives three illuminated arcade buttons:
 *   0 = all off, 1 = red, 2 = yellow, 3 = green  (single active light)
 *
 * Pins (as built):
 *   switches  RED=GPIO3  YEL=GPIO4  GRN=GPIO5   (INPUT_PULLUP, press = LOW, COM -> GND)
 *   lamps     RED=GPIO6  YEL=GPIO7  GRN=GPIO10
 *   onboard LED GPIO8 (INVERTED, LOW = ON) mirrors state != 0
 *
 * LAMP POLARITY: drivers are S8550 PNP (not the S8050 NPN on the schematic -
 * assortment-kit mixup, the soldered parts win). GPIO LOW = lamp ON,
 * HIGH = lamp OFF. Do not "fix" this to NPN logic.
 *
 * Button semantics (must match server.py's echo-suppression logic):
 *   press any button while state != 0 -> state = 0 (physical acknowledge)
 *   press a button while state == 0   -> state = that button's color
 *     (the server writes it back to 0; reserved "ping back" hook)
 * A BLE central can WRITE (0-3), READ, and gets NOTIFY on every change.
 */

#include <NimBLEDevice.h>

#define SVC_UUID   "6d5f0001-4b6b-4a3a-9e1e-2a7b1c9f0001"
#define STATE_UUID "6d5f0002-4b6b-4a3a-9e1e-2a7b1c9f0002"

const int NCH = 3;
const int BTN[NCH]  = {3, 4, 5};    // red, yellow, green
const int LAMP[NCH] = {6, 7, 10};   // red, yellow, green (LOW = ON, PNP)
const int LEDB = 8;                 // onboard LED, INVERTED (LOW = ON)

NimBLECharacteristic* stateChar = nullptr;
uint8_t state = 0;                  // 0=off, 1=red, 2=yellow, 3=green
bool connected = false;

// debounce, per button
int lastRead[NCH] = {HIGH, HIGH, HIGH};
uint32_t lastEdge[NCH] = {0, 0, 0};
bool handled[NCH] = {false, false, false};

void applyLamps() {
  for (int i = 0; i < NCH; i++)
    digitalWrite(LAMP[i], (state == i + 1) ? LOW : HIGH);   // PNP: LOW = ON
  digitalWrite(LEDB, state ? LOW : HIGH);                   // onboard: inverted
}

void pushState(bool doNotify) {
  stateChar->setValue(&state, 1);
  if (doNotify && connected) stateChar->notify();
}

class StateCallbacks : public NimBLECharacteristicCallbacks {
  void onWrite(NimBLECharacteristic* c, NimBLEConnInfo& info) override {
    std::string v = c->getValue();
    if (v.empty()) return;
    state = (v[0] <= 3) ? v[0] : 0;
    applyLamps();
    pushState(true);
    Serial.printf("write -> state %d\n", state);
  }
};

class ServerCallbacks : public NimBLEServerCallbacks {
  void onConnect(NimBLEServer* s, NimBLEConnInfo& i) override {
    connected = true; Serial.println("central connected");
  }
  void onDisconnect(NimBLEServer* s, NimBLEConnInfo& i, int reason) override {
    connected = false; Serial.println("central disconnected");
    NimBLEDevice::startAdvertising();
  }
};

void setup() {
  // Lamps OFF (HIGH) before anything else - latch the level, then enable output
  for (int i = 0; i < NCH; i++) {
    digitalWrite(LAMP[i], HIGH);
    pinMode(LAMP[i], OUTPUT);
    digitalWrite(LAMP[i], HIGH);
  }
  digitalWrite(LEDB, HIGH);
  pinMode(LEDB, OUTPUT);
  digitalWrite(LEDB, HIGH);
  for (int i = 0; i < NCH; i++) pinMode(BTN[i], INPUT_PULLUP);

  Serial.begin(115200);
  applyLamps();

  Serial.printf("pins -> BTN=%d/%d/%d  LAMP=%d/%d/%d (R/Y/G)  LEDB=%d\n",
                BTN[0], BTN[1], BTN[2], LAMP[0], LAMP[1], LAMP[2], LEDB);

  NimBLEDevice::init("WifeSignal");
  NimBLEDevice::setPower(ESP_PWR_LVL_P9);

  NimBLEServer* server = NimBLEDevice::createServer();
  server->setCallbacks(new ServerCallbacks());

  NimBLEService* svc = server->createService(SVC_UUID);
  stateChar = svc->createCharacteristic(STATE_UUID,
      NIMBLE_PROPERTY::READ | NIMBLE_PROPERTY::WRITE | NIMBLE_PROPERTY::NOTIFY);
  stateChar->setCallbacks(new StateCallbacks());
  pushState(false);
  svc->start();

  NimBLEAdvertising* adv = NimBLEDevice::getAdvertising();
  adv->addServiceUUID(SVC_UUID);
  adv->setMinInterval(160);   // 100 ms
  adv->setMaxInterval(320);   // 200 ms
  adv->setName("WifeSignal");
  adv->start();
  Serial.println("BLE up - advertising as WifeSignal");
}

void loop() {
  uint32_t now = millis();
  for (int i = 0; i < NCH; i++) {
    int r = digitalRead(BTN[i]);
    if (r != lastRead[i]) { lastRead[i] = r; lastEdge[i] = now; }
    if (now - lastEdge[i] > 40) {
      if (r == LOW && !handled[i]) {
        handled[i] = true;
        state = state ? 0 : (uint8_t)(i + 1);
        applyLamps();
        pushState(true);
        Serial.printf("press btn %d -> state %d\n", i + 1, state);
      } else if (r == HIGH) {
        handled[i] = false;
      }
    }
  }
  delay(5);
}

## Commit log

2026-08-15 Add RoboImplant: non-invasive spinal implant adjustment system
    Archival snapshot of a medical-device research prototype (~2012-2013):
    AVR firmware, Android clinician console, EAGLE PCB design, and SolidWorks
    enclosure for a motorized spinal distraction implant that lengthens a
    growing rod without surgery.
    Reorganized from a flat resources folder into discipline-oriented
    directories (firmware/, android/, hardware/, models/, docs/), stripped
    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
    [6mm_rod.SLDPRT, Metal Rod.skp, enclosure_battery_cover.SLDPRT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]
2026-08-15 Enable GitHub Pages: theme config and directory indexes
    Add _config.yml (primer theme) and README indexes for models/ and
    docs/motor/ so every directory linked from the project README resolves
    on the rendered site.
2026-08-15 Add screenshots and hardware photos
    Six original images: four app screens (procedure, service terminal,
    calibration, adjustment history) and two photos of the driver unit
    assembled and on the bench. Captions tie each to the technical narrative.
    Screenshots resized to 500px PNG; photos converted to JPEG at 1000px
    (4.2 MB -> 680 KB).
2026-08-15 Add case study PDF; correct hardware revisions and dose units
    Link the one-page case study from the project and portfolio pages.
    Reading it surfaced two errors in the README:
    - The two photos are v1 (3D-printed housing) and v2 (machined
    polycarbonate); v2 had been captioned as an *earlier* bench build.
    - Dose is entered in micrometres (~20 um increments), not millimetres;
    cumulative elongation is what's displayed in mm.
2026-08-15 Add 3dscanner: DIY turntable photogrammetry rig
    Five subsystems: an iOS camera server with a hand-rolled HTTP/1.1 stack,
    a Python session controller, Arduino IR turntable control, Apple Object
    Capture reconstruction, and PyMeshLab print preparation.
    Deployment specifics (signing team, device IDs, Tailscale addresses, serial
    ports) replaced with placeholders. Two STL sets removed for unverifiable
    provenance; see 3dscanner/NOTICE.md.
    [capture_remote_signals.ino, ir_blaster.ino, ir_dc_test.ino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]
2026-08-15 3dscanner: add rig photographs and captions
    Seven original photographs of the rig, subject, and output, integrated
    into the narrative rather than appended: the IR emitter beside the
    unobservable-actuator section, the turntable markers beside the
    what-breaks-a-solve lesson, and the slicer/print pair as the payoff.
    Adds an images rights statement to NOTICE.md.
2026-08-15 3dscanner: crop rig photo for a more legible hero
    The full light-tent frame rendered too small to read the ScannerCam lock
    rows or see the IR emitter. Adds a cropped view as the hero and in the
    iPhone README; the wide tent shot moves to the section about controlled
    optical conditions, where its caption actually belongs.
2026-08-15 3dscanner: fix inaccurate photo caption, tighten hero
    The turntable/Arduino photo was captioned "with the lights off" — wrong,
    inferred from the framing rather than observed. It is the same lit tent,
    just closer in. Rewritten short and explicit: the IR LED aimed at the
    turntable, and the codes learned from the remote with
    capture_remote_signals.ino. Hero caption trimmed to match.
2026-08-15 3dscanner: add one-page case study, reconcile README with it
    Renames the case study to match the roboimplant convention and links it
    first, as roboimplant does.
    The PDF documents the actual motivation, which the README had replaced
    with a generic cost argument: an artist needed larger and deeper variants
    of a commercially molded clay flower that existed only as a physical
    object. Corrected in the README, the index, and NOTICE.md — the subject
    is the reason the project exists, not an arbitrary test target.
    Also adds the AI-as-engineering-harness framing the PDF leads with, which
    the README omitted entirely.
2026-08-15 Add WifeSignal: BLE desk signal light, iOS app to custom PCB
    Third portfolio project. A three-colour desk lamp that lets one person in
    the house signal another how urgently they need them, without a phone
    notification: SwiftUI app -> aiohttp/bleak bridge on a Mac -> BLE -> an
    ESP32-C3 driving three illuminated arcade buttons on a custom PCB in a
    generated enclosure.
    Published as a scrubbed snapshot of a private repo, with no inherited
    history. Redacted throughout: Apple team ID, App Store Connect key and
    issuer IDs (now read from the environment), the Tailscale tailnet name,
    and absolute paths in the LaunchAgent. The internal handoff runbook is
    not published at all -- it carried the live AP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
    [WifeSignal.kicad_pcb, WifeSignal.kicad_sch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]
2026-08-15 wifesignal: add one-page case study PDF
    Matches the roboimplant / 3dscanner one-pager template: same A4 layout,
    accent colour, section rhythm (problem / approach / impact / pipeline /
    engineering architecture / technical scope) and footer.
